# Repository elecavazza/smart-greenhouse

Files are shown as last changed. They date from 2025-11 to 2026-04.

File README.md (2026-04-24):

# smart-greenhouse

Smart GreenHouse System Diagram with Wiring

As part of my Mechatronics Project I will be creating a Smart Automated Greenhouse.  
As part of this project there will be a number of systems:  

* Watering system
  * 5v pump with relay control
  * Water level sensor
  * Reservoir
  * Shower head
  * Soil moisture sensor
* Lighting System
  * 12V Grow LED Strip with relay
* Air Quality System
  * 5V Fan with relay
  * VOC, Temperature, Humidity Sensors
* User Interface
  * Touch screen

## Programming

### CYD ESP32-2432S028

To program the CYD ESP32-2432S028 we will be using Arduino C/C++.  
To upload code to the device we use the Arduino IDE to compile it and the Micro USB connector to upload it via serial.  
To get it to work:  

* upload at a baud rate of 115200  
* target board used is the `ESP32 Dev Module`
* the external dependencies are:  `lvgl`, `TFT_eSPI`, `XPT2046_Touchscreen`
* enable erase all flash on sketch upload

#### Arduino Setup

```bash
Arduino
Version: 2.3.7
Date: 2025-12-17T16:03:27.077Z (3 months ago)
CLI Version: 1.3.1

arduino-cli  Version: 1.4.1 Commit: Homebrew Date: 2026-01-19T16:11:40Z
{}

ID            Installed        Latest           Name
arduino:avr   1.8.6            1.8.7            Arduino AVR Boards
arduino:esp32 2.0.18-arduino.5 2.0.18-arduino.5 Arduino ESP32 Boards
esp32:esp32   3.3.5            3.3.7            esp32

Name                Installed   Available    Location Description
EspSoftwareSerial   8.1.0       -            user     -
lvgl                9.4.0       9.5.0        user     Full-featured Graphics Library for Em...
TFT_eSPI            2.5.43      -            user     -
XPT2046_Touchscreen 1.4         -            user     -

Port                            Protocol Type              Board Name FQBN Core
/dev/cu.Bluetooth-Incoming-Port serial   Serial Port       Unknown
/dev/cu.SoundcoreLifeP3         serial   Serial Port       Unknown
/dev/cu.StrawberryMoon          serial   Serial Port       Unknown
/dev/cu.debug-console           serial   Serial Port       Unknown
/dev/cu.usbserial-210           serial   Serial Port (USB) Unknown
```

```bash
arduino-cli version
arduino-cli config dump
arduino-cli core list
arduino-cli lib list
arduino-cli board list
```

### Raspberry Pi Pico

To program the Raspberry Pi Pico we will be using MicroPython.  
To upload code to the device we use the Thonny IDE and upload via the Micro USB connector.  

## Parts

### Electronics

Relays: 5v, 12, 24v etc:  
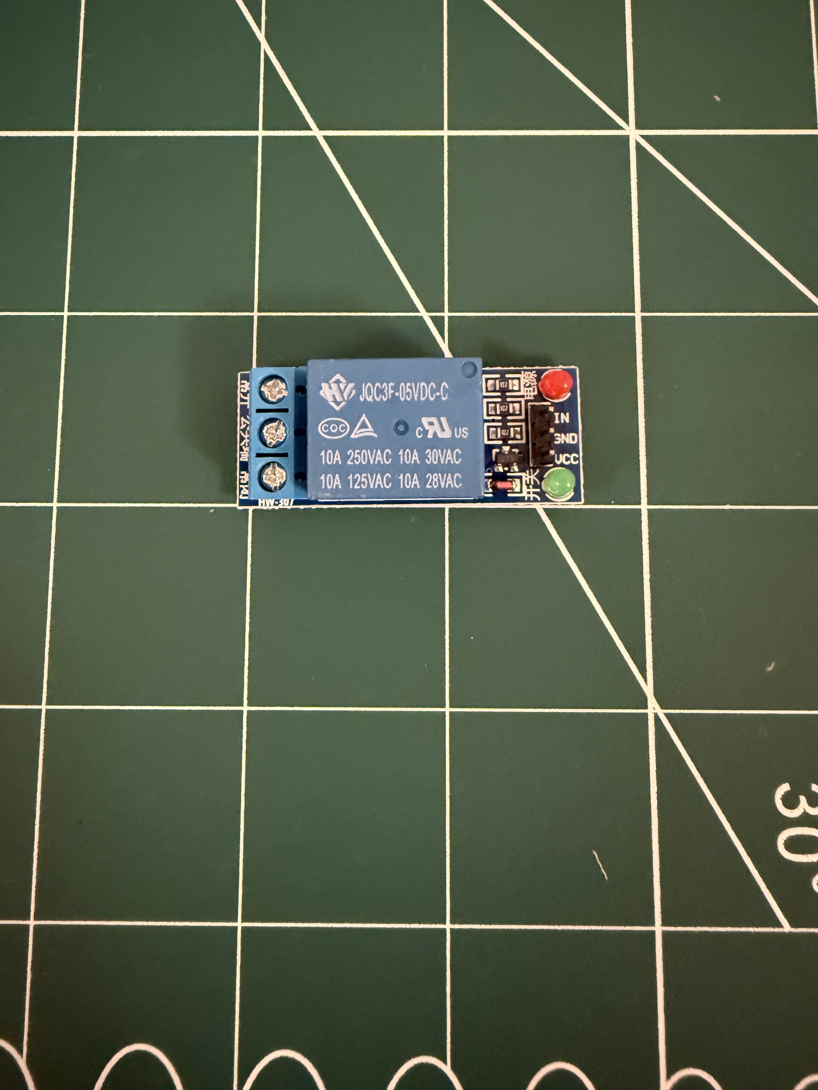
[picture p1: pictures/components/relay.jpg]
relay


5V Led Grow Strip:  
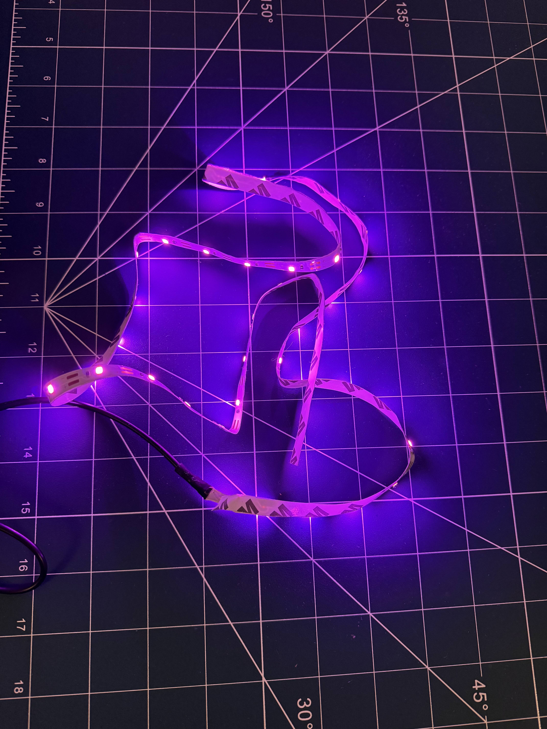
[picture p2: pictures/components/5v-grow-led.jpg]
5v led

12V Led Grow Strip:  
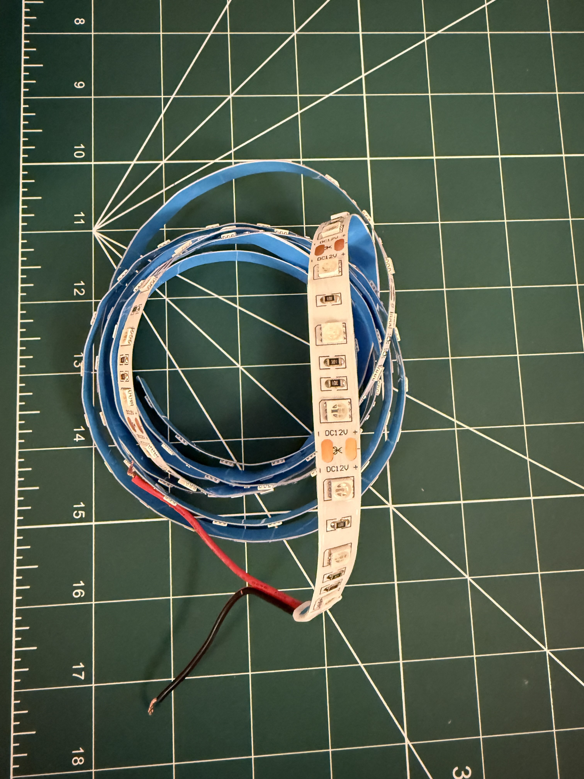
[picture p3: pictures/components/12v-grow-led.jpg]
12v

CO2 Sensor:  
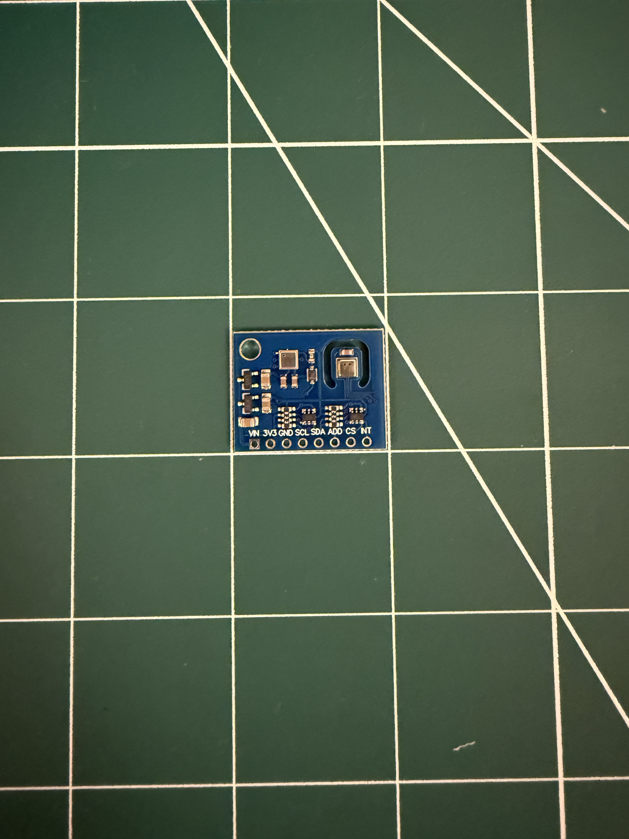
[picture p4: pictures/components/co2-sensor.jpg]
co2 sensor


Soil Moisture Sensor:  
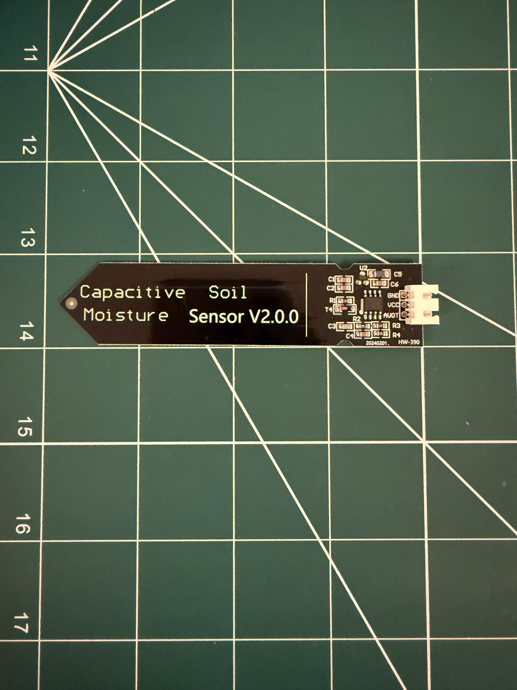
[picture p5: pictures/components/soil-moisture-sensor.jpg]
soil moisture sensor


Submersible Pump:  
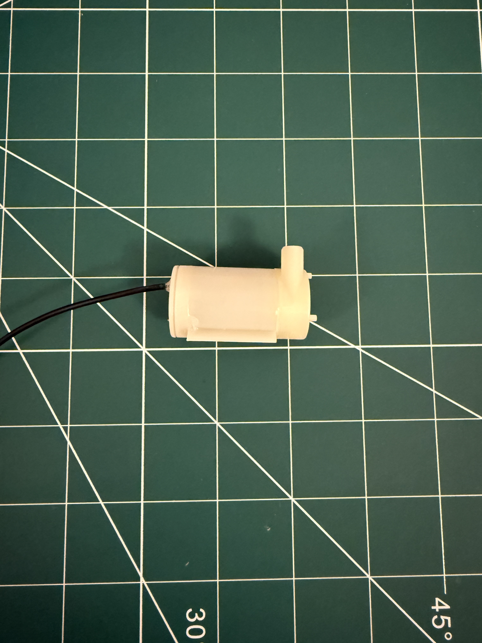
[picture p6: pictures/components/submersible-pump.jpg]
submersible pump


Water Level Sensor:  
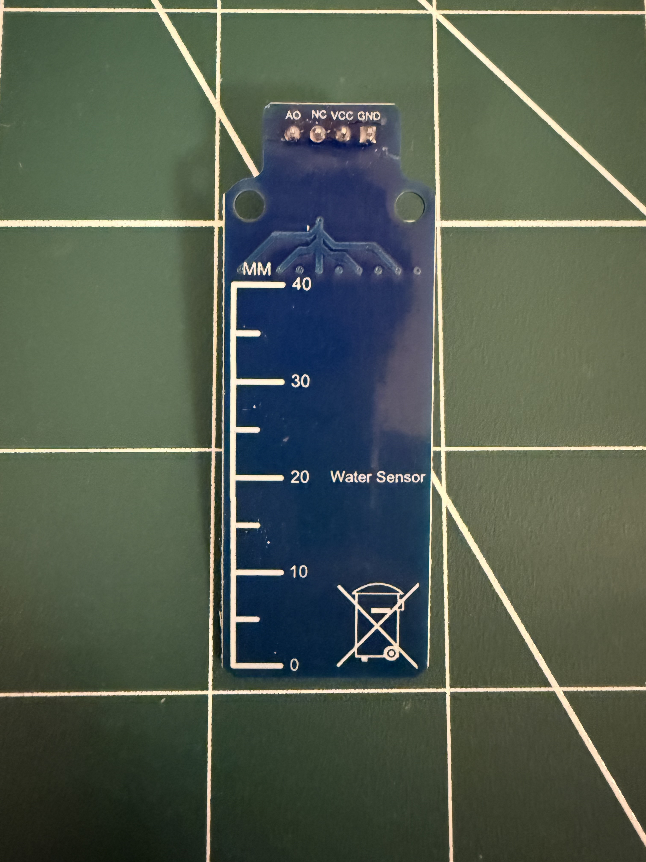
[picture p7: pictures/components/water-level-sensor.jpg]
water-level-sensor


Temperature and Humidity Sensor:  
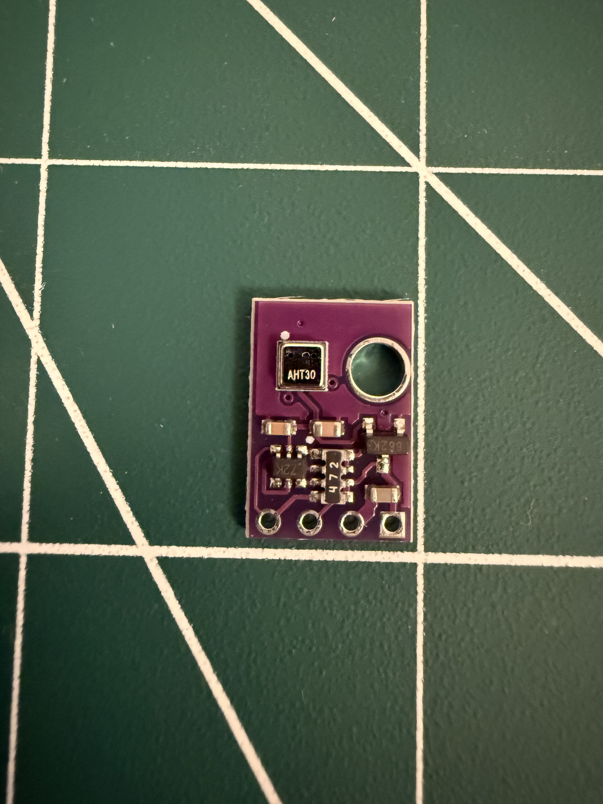
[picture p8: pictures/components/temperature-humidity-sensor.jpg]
temperature-humidity-sensor


### GreenHouse/Plant

Ikea Bittergurka Pot:
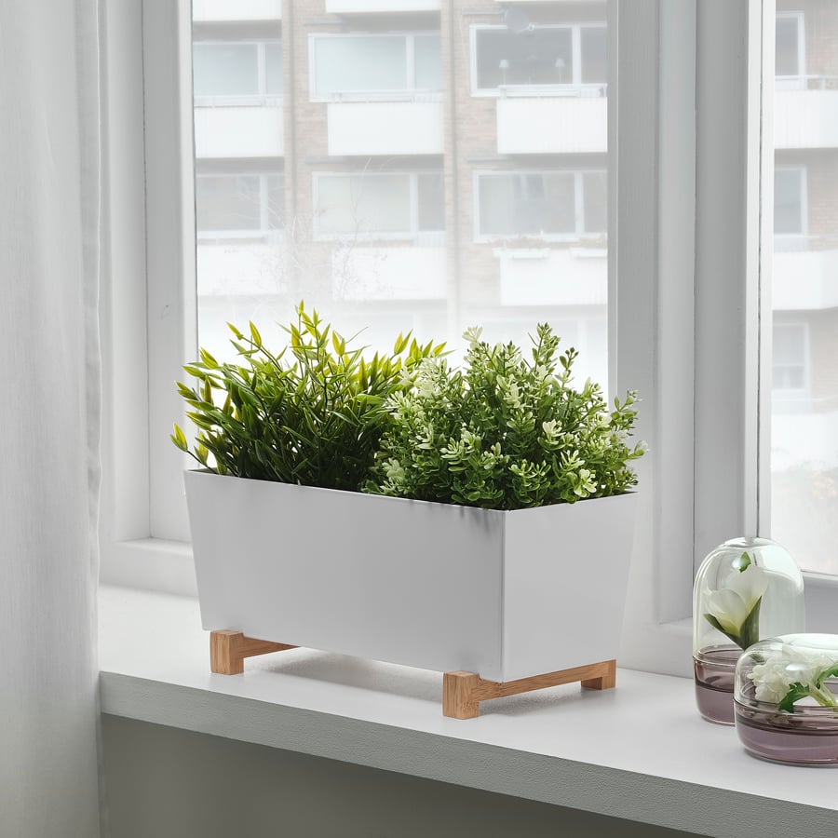
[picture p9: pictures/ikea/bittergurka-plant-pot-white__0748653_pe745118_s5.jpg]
Ikea Bittergurka

Ikea Bittergurka Dimensions

[3D Model](./3d-models/bittergurka-plant-pot-white-80285787.fbx)

Ikea Akerbaer Greenhouse:
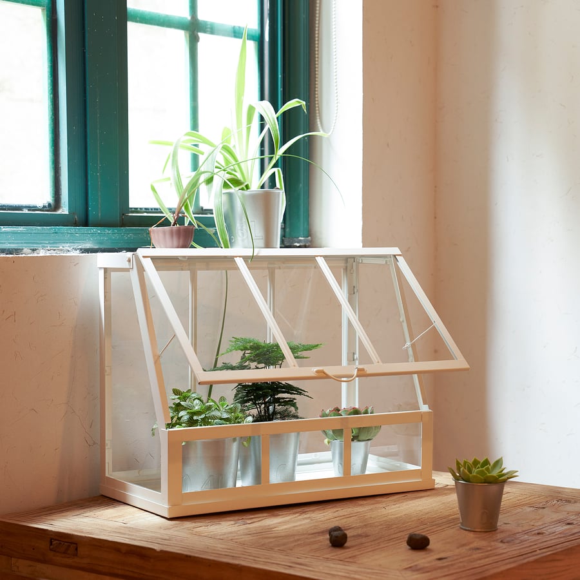
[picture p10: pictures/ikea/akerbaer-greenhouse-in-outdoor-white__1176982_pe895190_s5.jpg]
Ikea Akerbaer

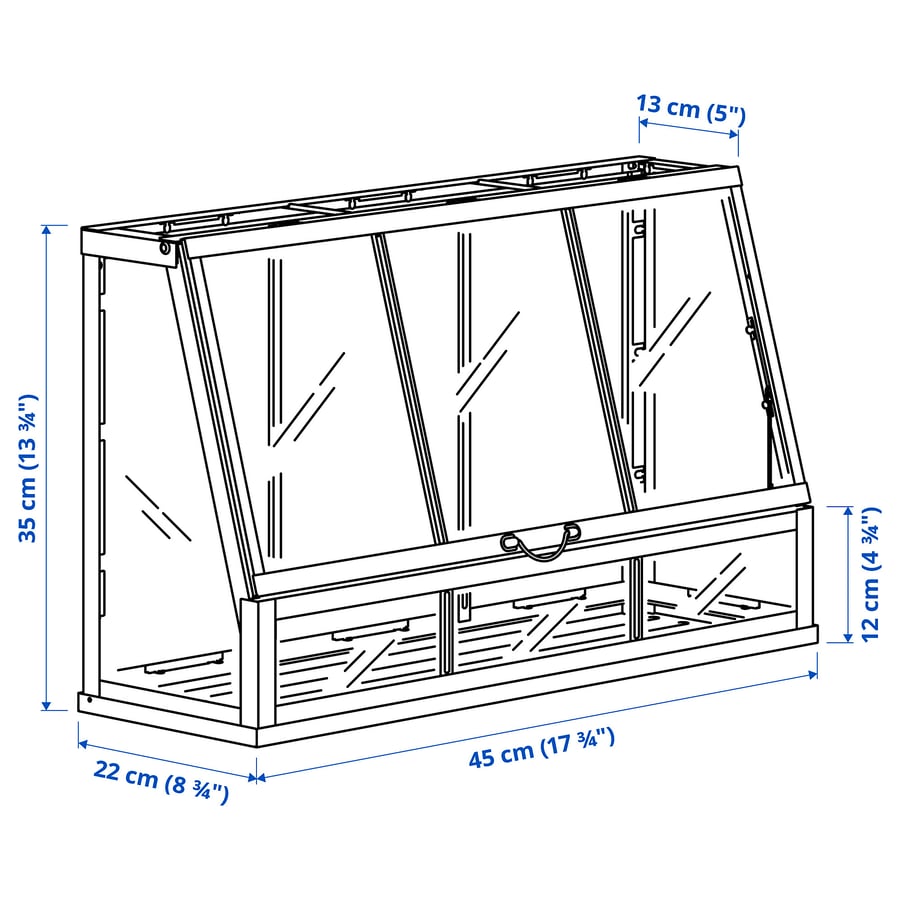
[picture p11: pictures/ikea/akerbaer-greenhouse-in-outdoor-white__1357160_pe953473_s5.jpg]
Ikea Akerbaer Dimensions


[3D Model](./3d-models/akerbar-white-30537170.fbx)

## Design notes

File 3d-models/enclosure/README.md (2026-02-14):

# Enclosure Design

We are currently on revision 2.  
There will need to be atleast one other revision.  

Chnages needed:

* Hole for Soil Sensor Connector
  * 3 pin
* Hole for Light Sensor Connector
  * 2 pin
* Switch to 3 pin for water level
  * Currently using 2 of the 2 pin

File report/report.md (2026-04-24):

# Smart Greenhouse Control System

## Mechatronics Project Report

---

## Table of Contents

1. [Introduction](#1-introduction)
2. [System Architecture](#2-system-architecture)
3. [Hardware Design](#3-hardware-design)
4. [Physical Assembly](#4-physical-assembly)
5. [Software Design](#5-software-design)
6. [Communication Protocol](#6-communication-protocol)
7. [3D Printed Components](#7-3d-printed-components)
8. [Bill of Materials](#8-bill-of-materials)
9. [Challenges & Solutions](#9-challenges--solutions)
10. [Results & Discussion](#10-results--discussion)
11. [Conclusion & Future Work](#11-conclusion--future-work)
12. [References](#12-references)

---

## 1. Introduction

### 1.1 Project Overview

This project presents the design and implementation of a Smart Automated Greenhouse system capable of autonomously maintaining optimal growing conditions for plants. The system integrates multiple sensors, actuators, and microcontrollers to create a closed loop control system that monitors and regulates watering, lighting, and air quality without manual intervention.

### 1.2 Motivation

Indoor herb gardening presents several challenges for hobbyists and enthusiasts:

- **Inconsistent watering**: Over or under watering is a common cause of plant death
- **Inadequate lighting**: Indoor environments often lack sufficient natural light for healthy plant growth
- **Poor air circulation**: Stagnant air can lead to fungal growth and humidity problems

A smart greenhouse addresses these challenges by automating the monitoring and control of environmental conditions, ensuring plants receive optimal care even when the owner is away.

### 1.3 Objectives

The primary objectives of this project were to:

1. **Design and build an automated watering system** that delivers water based on soil moisture levels using pulse based irrigation to prevent overwatering
2. **Implement automatic grow lighting** that supplements natural light when ambient levels are insufficient
3. **Create an air quality management system** that controls temperature and humidity through ventilation
4. **Develop a touchscreen user interface** for monitoring sensor data and controlling system functions
5. **Integrate all subsystems** into a cohesive, reliable, and cost effective solution using readily available components

### 1.4 Target Application

The system is designed for growing culinary herbs such as basil and mint, which have moderate water requirements and benefit from consistent environmental conditions. The IKEA ÅKERBÄR greenhouse provides an aesthetically pleasing enclosure suitable for indoor use.

---

## 2. System Architecture

### 2.1 High Level Overview

The Smart Greenhouse employs a dual microcontroller architecture that separates concerns between user interface and control logic:

```mermaid
flowchart TB
    subgraph UI["User Interface Layer"]
        ESP32["ESP32-2432S028<br/>(Cheap Yellow Display)"]
        Touch["Touch Screen<br/>320x240 LCD"]
        LVGL["LVGL Graphics Library"]
    end
    
    subgraph Control["Control Layer"]
        Pico["Raspberry Pi Pico W"]
        Controller["GreenhouseController"]
    end
    
    subgraph Subsystems["Automated Subsystems"]
        Water["WateringSystem"]
        Air["AirQualitySystem"]
        Light["LightingSystem"]
    end
    
    subgraph Sensors["Sensors"]
        Soil["Soil Moisture<br/>(Capacitive)"]
        WaterLvl["Water Level"]
        LDR["Light Sensor<br/>(LDR)"]
        TempHum["Temp & Humidity<br/>(AHT21)"]
    end
    
    subgraph Actuators["Actuators"]
        Pump["5V Submersible<br/>Pump"]
        Fan["5V Cooling<br/>Fans"]
        LED["12V Grow<br/>LED Strip"]
    end
    
    ESP32 <-->|"UART<br/>115200 baud"| Pico
    Touch --> ESP32
    LVGL --> ESP32
    
    Pico --> Controller
    Controller --> Water & Air & Light
    
    Water --> Soil & WaterLvl
    Water --> Pump
    Air --> TempHum
    Air --> Fan
    Light --> LDR
    Light --> LED
```

### 2.2 Design Rationale

The dual controller architecture was chosen for several reasons:

| Aspect | ESP32 (CYD) | Raspberry Pi Pico W |
|---|---|---|
| **Primary Role** | User Interface | Sensor/Actuator Control |
| **Programming Language** | Arduino C++ | MicroPython |
| **Key Libraries** | LVGL, TFT_eSPI | Machine, Custom Modules |
| **Processing Focus** | Graphics Rendering | Real time Control |
| **Communication** | UART TX/RX | UART TX/RX |

This separation allows:

- The ESP32 to focus on smooth UI rendering without being interrupted by sensor polling
- The Pico to maintain precise timing for sensor readings and actuator control
- Independent development and testing of UI and control logic
- Easier debugging of each subsystem

### 2.3 Subsystem Overview

The system comprises three automated subsystems:

#### Watering System

- **Trigger Condition**: Soil moisture below threshold AND water available in reservoir
- **Action**: Pulse based watering (500ms burst with 30 second cooldown)
- **Safety Feature**: Prevents pumping when reservoir is empty

#### Air Quality System

- **Trigger Conditions**:
  - Temperature > 25°C (too hot)
  - Humidity > 70% (too humid)
  - Humidity < 50% (too dry - circulate air)
- **Action**: Activate ventilation fans
- **Override**: Fan stays off if temperature < 20°C (preserve heat)

#### Lighting System

- **Trigger Condition**: Ambient light below threshold
- **Action**: Activate 12V grow LED strip

---

## 3. Hardware Design

### 3.1 Component Selection

#### 3.1.1 Microcontrollers

**Raspberry Pi Pico W**

- Dual-core ARM Cortex-M0+ @ 133MHz
- 264KB SRAM, 2MB Flash
- 26 GPIO pins with 3 ADC channels
- Built in WiFi (802.11n) for future expansion
- MicroPython support for rapid development

**ESP32-2432S028 (Cheap Yellow Display)**

- ESP32-WROOM-32 module
- Integrated 2.8" 320x240 TFT LCD with ILI9341 driver
- XPT2046 resistive touch controller
- Built in USB Serial for programming
- Cost effective all in one display solution

#### 3.1.2 Sensors

| Sensor | Type | Interface | Purpose |
|---|---|---|---|
| Capacitive Soil Moisture | Analog | ADC (GP26) | Measure soil water content |
| Water Level Sensor | Analog | ADC (GP28) | Monitor reservoir level |
| LDR Light Sensor | Analog | ADC (GP27) | Measure ambient light |
| AHT21 | Digital I2C | GP4/GP5 | Temperature & humidity |

**Sensor Specifications:**

*Capacitive Soil Moisture Sensor*
- Operating Voltage: 3.3V - 5V
- Output: Analog (inversely proportional to moisture)
- Calibration: Air ~65000 ADC, Water ~15000 ADC

*AHT21 Temperature & Humidity Sensor*
- Temperature Range: -40°C to +85°C (±0.3°C accuracy)
- Humidity Range: 0-100% RH (±2% accuracy)
- I2C Address: 0x38

#### 3.1.3 Actuators

| Actuator | Voltage | Control | Purpose |
|---|---|---|---|
| Submersible Pump | 5V | Relay (GP14) | Water delivery |
| Cooling Fans (×2) | 5V | Relay (GP15) | Ventilation |
| Grow LED Strip (2m) | 12V | Relay (GP10) | Supplemental lighting |

### 3.2 Pin Assignments

#### Raspberry Pi Pico W Pin Configuration

```
                    ┌─────────────────────┐
                    │   Raspberry Pi      │
                    │      Pico W         │
                    ├─────────────────────┤
         UART TX ──►│ GP0            GP26 │◄── Soil Moisture (ADC)
         UART RX ──►│ GP1            GP27 │◄── Light Sensor (ADC)
                    │ GND            GP28 │◄── Water Level (ADC)
                    │ GP2            GND  │
                    │ GP3            3V3  │
         I2C SDA ──►│ GP4            VREF │
         I2C SCL ──►│ GP5            GP22 │
                    │ GND            GND  │
                    │ GP6            GP21 │
                    │ GP7            GP20 │
                    │ GP8            GP19 │
                    │ GP9            GP18 │
                    │ GND            GND  │
     Light Relay ──►│ GP10           GP17 │
                    │ GP11           GP16 │
                    │ GP12           GP15 │◄── Fan Relay
                    │ GP13           GP14 │◄── Pump Relay
                    │ GND            GND  │
                    └─────────────────────┘
```

#### ESP32 CYD UART Connection

| ESP32 Pin | Function | Connection |
|---|---|---|
| GPIO 35 (RX_P3) | UART Receive | Pico GP0 (TX) |
| GPIO 22 (TX_P3) | UART Transmit | Pico GP1 (RX) |

### 3.3 Power Distribution

The system uses two USB-C Power Delivery boards to provide multiple voltage rails:

```mermaid
flowchart LR
    subgraph Input["Power Input"]
        USB1["USB-C PD Board 1<br/>(5V Output)"]
        USB2["USB-C PD Board 2<br/>(12V Output)"]
    end
    
    subgraph Rails["Voltage Rails"]
        V3["3.3V Rail<br/>(from Pico)"]
        V5["5V Rail"]
        V12["12V Rail"]
    end
    
    subgraph Loads5V["5V Loads"]
        Pico2["Pico W"]
        ESP["ESP32 CYD"]
        Fans2["Cooling Fans"]
        Pump2["Water Pump"]
        Relay["Relay Modules"]
    end
    
    subgraph Loads12V["12V Loads"]
        LEDStrip["Grow LED Strip"]
    end
    
    subgraph Loads3V["3.3V Loads"]
        Sensors2["Analog Sensors"]
        LevelShift["Level Shifters"]
    end
    
    USB1 --> V5
    USB2 --> V12
    Pico2 --> V3
    
    V5 --> Pico2 & ESP & Fans2 & Pump2 & Relay
    V12 --> LEDStrip
    V3 --> Sensors2 & LevelShift
```

### 3.4 Level Shifting

The 5V relay modules require 5V logic signals, but the Pico W operates at 3.3V. Bidirectional level shifters are used to convert:

- 3.3V Pico GPIO → 5V Relay trigger signals

---

## 4. Physical Assembly

### 4.1 Greenhouse Structure

The project utilises IKEA furniture as the foundation:

**IKEA ÅKERBÄR Greenhouse**
- Dimensions: 45 × 22 × 35 cm
- Material: Powder coated steel with glass panels
- Provides enclosed environment with ventilation options
- Price: €19.00

**IKEA BITTERGURKA Plant Pot**
- Dimensions: 32 × 15 × 15 cm
- Material: Powder coated steel
- Positioned centrally within greenhouse
- Price: €12.00

### 4.2 Component Placement

```mermaid
flowchart TB
    subgraph Greenhouse["IKEA ÅKERBÄR Greenhouse (Front View)"]
        subgraph Top["Top Section"]
            CYD["ESP32 CYD Display<br/>(On top of greenhouse)"]
            LEDs["12V Grow LED Strip"]
            LDRTop["Light Sensor (LDR)"]
        end
        
        subgraph Middle["Middle Section"]
            Pot["BITTERGURKA Pot<br/>with Basil Plant"]
            SoilSensor["Soil Moisture Sensor"]
            Showerhead["Magnetic Showerhead"]
        end
        
        subgraph Back["Back Wall (Interior)"]
            FansBack["Cooling Fans (×2)"]
        end
        
        subgraph Right["Right Side"]
            Reservoir["Glass Jar Reservoir"]
            PumpR["Submersible Pump"]
            WaterSensorR["Water Level Sensor"]
        end
    end
    
    subgraph External["External (Back of Greenhouse)"]
        Enclosure["Project Box Enclosure"]
    end
    
    Top --> Middle
    Middle --> Right
    Back --> Middle
    Greenhouse --> External
```

### 4.3 Enclosure Contents

The 3D printed project box mounted on the back of the greenhouse contains:

| Component | Purpose |
|---|---|
| Breadboard | Component interconnection |
| Raspberry Pi Pico W | Main controller |
| Level Shifters | 3.3V ↔ 5V conversion |
| Relay Modules (×3) | Pump, Fan, LED control |
| AHT21 Sensor | Temperature & humidity monitoring |
| USB-C PD Board (5V) | 5V power supply |
| USB-C PD Board (12V) | 12V power supply |

### 4.4 Wiring Strategy

**Connector Types:**
- **JST Connectors**: Used throughout for modularity and easy disconnection
- **RJ45 Keystone Jacks**: Used for longer cable runs (CYD power/data, LED/LDR)

**Cable Routing:**
- All wires routed under the back wall to the enclosure underside
- Standard white Ethernet cabling for RJ45 connections
- 24 AWG white wire for general connections

**RJ45 Usage:**
1. **CYD Connection**: Power (5V, GND) + Data (UART TX, RX)
2. **LED/LDR Connection**: 12V, GND, LDR signal

---

## 5. Software Design

### 5.1 Raspberry Pi Pico W (MicroPython)

#### 5.1.1 Software Architecture

The Pico software follows a modular, object oriented design:

```mermaid
classDiagram
    class main {
        +main()
    }
    
    class GreenhouseController {
        -uart: UARTCommunication
        -wateringSystem: WateringSystem
        -airQualitySystem: AirQualitySystem
        -lightingSystem: LightingSystem
        -led: Pin
        +run()
        +sendAllSensorData()
        +sendAllStatus()
        -_processCommands()
        -_handleCommand()
        -_readAllSensors()
        -_updateSystems()
    }
    
    class WateringSystem {
        -pump: Relay
        -soilSensor: SoilMoistureSensor
        -waterLevelSensor: WaterLevelSensor
        -enabled: bool
        +enable()
        +disable()
        +update()
        +pulse()
        +getSoilMoisturePercent()
        +getWaterLevelPercent()
    }
    
    class AirQualitySystem {
        -fan: Relay
        -sensor: TemperatureAndHumiditySensor
        -enabled: bool
        +enable()
        +disable()
        +update()
        +getTemperature()
        +getHumidity()
    }
    
    class LightingSystem {
        -light: Relay
        -sensor: LightSensor
        -enabled: bool
        +enable()
        +disable()
        +update()
        +getLightLevelPercent()
    }
    
    class UARTCommunication {
        -uart: UART
        +send()
        +sendSensorData()
        +sendStatus()
        +receive()
        +receiveAll()
    }
    
    class Relay {
        -pin: Pin
        -active_low: bool
        +turnOn()
        +turnOff()
    }
    
    main --> GreenhouseController
    GreenhouseController --> WateringSystem
    GreenhouseController --> AirQualitySystem
    GreenhouseController --> LightingSystem
    GreenhouseController --> UARTCommunication
    WateringSystem --> Relay
    AirQualitySystem --> Relay
    LightingSystem --> Relay
```

#### 5.1.2 Main Control Loop

The main control loop executes the following sequence:

```python
while True:
    # 1. Process incoming UART commands from ESP32
    _processCommands()
    
    # 2. Read sensors periodically (every 2 seconds)
    if time_since_last_read >= SENSOR_READ_INTERVAL_MS:
        _readAllSensors()
    
    # 3. Run automatic control logic for all enabled systems
    wateringSystem.update()
    airQualitySystem.update()
    lightingSystem.update()
    
    # 4. Send data to ESP32 periodically (every 5 seconds)
    if time_since_last_send >= DATA_SEND_INTERVAL_MS:
        sendAllSensorData()
    
    # 5. Small delay to prevent busy loop
    time.sleep_ms(100)
```

#### 5.1.3 Control Algorithms

**Watering System - Pulse Irrigation:**

```python
def update(self):
    if not self.enabled:
        return
    
    # Check conditions
    if not self.isSoilDry():
        return  # Soil is moist enough
    
    if not self.hasWater():
        return  # Reservoir empty - safety check
    
    if time_since_last_pulse < PUMP_COOLDOWN_MS:
        return  # Still in cooldown period
    
    # Perform pulse watering
    self.pulse()  # 500ms burst

def pulse(self):
    self.pump.turnOn()
    time.sleep_ms(PUMP_PULSE_MS)  # 500ms
    self.pump.turnOff()
    self.lastPulseTime = time.ticks_ms()
```

**Air Quality System - Threshold Based Control:**

| Condition | Action | Reason |
|---|---|---|
| Temp > 25°C | Fan ON | Too hot |
| Temp < 20°C | Fan OFF | Preserve heat |
| Humidity > 70% | Fan ON | Too humid |
| Humidity < 50% | Fan ON | Circulate air |
| Otherwise | Fan OFF | Conditions optimal |

**Lighting System - Light Level Control:**

```python
def update(self):
    if not self.enabled:
        return
    
    rawValue = self.sensor.readRaw()
    isDark = rawValue < LIGHT_LOW_THRESHOLD
    
    if isDark:
        self._setLight(True)   # Turn on grow light
    else:
        self._setLight(False)  # Natural light sufficient
```

#### 5.1.4 Configuration Parameters

Key thresholds and timing values defined in [`config.py`](../code/raspberry-pi-pico/main/config.py):

| Parameter | Value | Description |
|---|---|---|
| `SOIL_DRY_THRESHOLD` | 40000 | ADC value indicating dry soil |
| `WATER_LOW_THRESHOLD` | 15000 | ADC value indicating empty reservoir |
| `TEMP_HIGH_THRESHOLD` | 25.0°C | Temperature to trigger cooling |
| `TEMP_LOW_THRESHOLD` | 20.0°C | Temperature to preserve heat |
| `HUMIDITY_HIGH_THRESHOLD` | 70% | Humidity to trigger ventilation |
| `HUMIDITY_LOW_THRESHOLD` | 50% | Low humidity threshold |
| `LIGHT_LOW_THRESHOLD` | 1000 | ADC value indicating darkness |
| `PUMP_PULSE_MS` | 500ms | Duration of pump burst |
| `PUMP_COOLDOWN_MS` | 30000ms | Minimum time between pulses |
| `SENSOR_READ_INTERVAL_MS` | 2000ms | Sensor polling interval |
| `DATA_SEND_INTERVAL_MS` | 5000ms | ESP32 update interval |

### 5.2 ESP32 CYD (Arduino/LVGL)

#### 5.2.1 User Interface Design

The touch screen interface uses the LVGL (Light and Versatile Graphics Library) to provide three main screens:

**Dashboard Tab**: Sensor Readings Display:

- Temperature (°C)
- Humidity (%)
- Soil Moisture (%)
- Water Level (%)

**Auto Tab**: Automatic System Control:

- Watering System toggle (enable/disable automatic control)
- Lighting System toggle
- Air Quality System toggle
- Status indicators (LED on/off)
- Trigger condition descriptions

**Manual Tab**: Direct Device Control:

- LED toggle (on/off)
- Fan toggle (on/off)
- Pump pulse trigger (momentary button)

#### 5.2.2 UI Implementation

```cpp
void create_gui() {
    tabview = lv_tabview_create(lv_screen_active());
    lv_tabview_set_tab_bar_size(tabview, 26);

    lv_obj_t *dash = lv_tabview_add_tab(tabview, "Dashboard");
    lv_obj_t *ctrl = lv_tabview_add_tab(tabview, "Auto");
    lv_obj_t *opts = lv_tabview_add_tab(tabview, "Manual");

    create_dashboard(dash);  // Sensor readings
    create_auto(ctrl);       // System toggles
    create_manual(opts);     // Direct controls
}
```

#### 5.2.3 Dependencies

| Library | Version | Purpose |
|---|---|---|
| LVGL | 9.4.0 | Graphics rendering |
| TFT_eSPI | 2.5.43 | Display driver |
| XPT2046_Touchscreen | 1.4 | Touch input |

---

## 6. Communication Protocol

### 6.1 UART Configuration

| Parameter | Value |
|---|---|
| Baud Rate | 115200 |
| Data Bits | 8 |
| Parity | None |
| Stop Bits | 1 |
| Line Terminator | `\n` (newline) |

### 6.2 Message Format

All messages are ASCII text terminated with a newline character.

#### 6.2.1 Sensor Data (Pico → ESP32)

```
SENSOR:<TYPE>:<VALUE>
```

| Type | Example | Description |
|---|---|---|
| TEMP | `SENSOR:TEMP:24.5` | Temperature in °C |
| HUMIDITY | `SENSOR:HUMIDITY:65.0` | Relative humidity % |
| SOIL | `SENSOR:SOIL:45.0` | Soil moisture % |
| WATER | `SENSOR:WATER:80.0` | Water level % |

#### 6.2.2 Status Updates (Pico → ESP32)

```
STATUS:<SYSTEM>:<STATE>
```

| System | States | Example |
|---|---|---|
| WATER | ON/OFF | `STATUS:WATER:ON` |
| LIGHT | ON/OFF | `STATUS:LIGHT:OFF` |
| AIR | ON/OFF | `STATUS:AIR:ON` |

#### 6.2.3 Commands (ESP32 → Pico)

**Request Commands:**
| Command | Response |
|---|---|
| `REQ:SENSORS` | All sensor data |
| `REQ:STATUS` | All system statuses |

**System Control Commands:**
| Command | Action |
|---|---|
| `CMD:WATER:ON` | Enable watering system |
| `CMD:WATER:OFF` | Disable watering system |
| `CMD:LIGHT:ON` | Enable lighting system |
| `CMD:LIGHT:OFF` | Disable lighting system |
| `CMD:AIR:ON` | Enable air quality system |
| `CMD:AIR:OFF` | Disable air quality system |

**Manual Device Commands:**
| Command | Action |
|---|---|
| `CMD:LED:ON` | Turn grow LED on |
| `CMD:LED:OFF` | Turn grow LED off |
| `CMD:FAN:ON` | Turn fan on |
| `CMD:FAN:OFF` | Turn fan off |
| `CMD:PUMP:PULSE` | Trigger pump pulse |

### 6.3 Communication Flow

```mermaid
sequenceDiagram
    participant ESP32 as ESP32 (UI)
    participant Pico as Pico (Controller)
    participant Sensors
    participant Actuators

    Note over ESP32,Pico: Startup Sequence
    Pico->>ESP32: PICO:READY
    ESP32->>Pico: REQ:SENSORS
    ESP32->>Pico: REQ:STATUS
    
    Note over ESP32,Pico: Normal Operation (every 5s)
    Pico->>Sensors: Read all sensors
    Sensors-->>Pico: Sensor values
    Pico->>ESP32: SENSOR:TEMP:24.5
    Pico->>ESP32: SENSOR:HUMIDITY:65.0
    Pico->>ESP32: SENSOR:SOIL:45.0
    Pico->>ESP32: SENSOR:WATER:80.0
    
    Note over ESP32,Pico: User Interaction
    ESP32->>Pico: CMD:WATER:ON
    Pico->>Actuators: Enable watering system
    Pico->>ESP32: STATUS:WATER:ON
    
    Note over ESP32,Pico: Manual Control
    ESP32->>Pico: CMD:PUMP:PULSE
    Pico->>Actuators: Pump ON (500ms)
    Pico->>Actuators: Pump OFF
```

---

## 7. 3D Printed Components

### 7.1 Electronics Enclosure

The electronics enclosure was designed using **OpenSCAD** with the **YAPP (Yet Another Parametric Projectbox)** generator library.

#### 7.1.1 Design Evolution

| Version | Changes |
|---|---|
| v1 | Initial design with basic dimensions |
| v2 | Adjusted internal standoffs |
| v3 | Final version with connector cutouts |

#### 7.1.2 Features

- Parametric design allowing easy modifications
- Separate lid and base for easy assembly
- Cutouts for:
  - RJ45 keystone jacks
  - JST connectors
  - Ventilation

#### 7.1.3 Files

- [`design-v3.scad`](../3d-models/enclosure/design-v3.scad) - OpenSCAD source
- [`design-v3-bottom.stl`](../3d-models/enclosure/design-v3-bottom.stl) - Base STL
- [`design-v3-lid.stl`](../3d-models/enclosure/design-v3-lid.stl) - Lid STL

#### 7.1.4 Planned Improvements

As noted in the enclosure README, future revisions will add:

- Hole for soil sensor connector (3-pin)
- Hole for light sensor connector (2-pin)
- Switch water level connector to 3-pin (currently using 2× 2-pin)

### 7.2 Showerhead

A custom showerhead was designed using **Fusion 360** for even water distribution over the soil surface.

#### 7.2.1 Design Specifications

- **Shape**: Rectangular box with internal cavity
- **Water Inlet**: Hollow cylinder into cavity
- **Water Outlets**: Holes drilled in bottom (post-printing)
- **Mounting**: Magnets glued to 3D model for easy attachment/removal

#### 7.2.2 Attachment Method

Magnets are glued to the showerhead body, allowing it to:

- Attach securely to the steel BITTERGURKA pot rim
- Be easily removed for cleaning or maintenance
- Self align with the planting area

---

## 8. Bill of Materials

### 8.1 Complete Parts List

| Item | Source | Qty | Unit Cost (€) | Total (€) |
|---|---|-----|---|---|
| 5V Relay | AliExpress | 2 | 1.50 | 3.00 |
| Soil Moisture Sensor | AliExpress | 5 | - | 3.23 |
| 12V Grow LED (2m) | AliExpress | 1 | 3.55 | 3.55 |
| 24 AWG White Wire (5m) | AliExpress | 1 | 2.34 | 2.34 |
| Cheap Yellow Display (CYD) | AliExpress | 1 | 9.99 | 9.99 |
| 5V Fans | Amazon | 2 | - | 6.54 |
| 5V Submersible Pumps | Amazon | 5 | - | 6.99 |
| Tubing | AliExpress | 1 | 2.00 | 2.00 |
| Water Level Sensors | AliExpress | 5 | - | 2.18 |
| RJ45 Keystone Jack | Temu | 10 | - | 5.08 |
| Adhesive Cable Clips | Temu | 50 | - | 1.72 |
| Heat Shrink Sleeve | Temu | 580 | - | 2.69 |
| Welding Heat Shrink | Temu | 1 | - | 4.91 |
| JST Connectors and Cables | Temu | 1 | - | 4.76 |
| Breadboard | Temu | 1 | - | 1.19 |
| USB-C PD Board | AliExpress | 5 | - | 4.71 |
| Temp/Humidity/CO2 Sensor (ENS160+AHT21) | AliExpress | 1 | - | 4.85 |
| Pi Pico | AliExpress | 5 | - | 9.00 |
| Level Shifter | AliExpress | 10 | - | 2.28 |
| IKEA BITTERGURKA Plant Pot | IKEA | 1 | 12.00 | 12.00 |
| IKEA ÅKERBÄR Greenhouse | IKEA | 1 | 19.00 | 19.00 |

### 8.2 Cost Summary

| Category | Cost (€) |
|---|---|
| Electronics & Sensors | €66.26 |
| Wiring & Connectors | €19.16 |
| Mechanical (IKEA) | €31.00 |
| **TOTAL** | **€112.01** |

*Note: Some items purchased in bulk quantities for spare parts and future projects.*

---

## 9. Challenges & Solutions

### 9.1 Electrical Challenges

#### 9.1.1 Loose Connections

**Problem**: Intermittent issues caused by loose wire connections on the breadboard, leading to unreliable sensor readings and actuator control.

**Solution**: Implemented cable clamps and strain relief to ensure secure, consistent connections. JST connectors were added at key points for modularity while maintaining connection integrity.

#### 9.1.2 USB-PD Power Compatibility

**Problem**: Not all USB power bricks properly support USB Power Delivery for the 12V rail needed by the LED strip. One power supply incorrectly output 15V, risking damage to components.

**Solution**: Tested multiple power supplies to identify compatible units. Selected verified USB-PD chargers that correctly negotiate and output 12V. Always verify output voltage before connecting loads.

#### 9.1.3 Power Surge Serial Issues

**Problem**: Power surges when actuators switch caused serial logging output to break, making debugging difficult. This occurred due to a single 5V line powering the Pico, ESP32, fans, relays, and pump.

**Solution**:  

- Added decoupling capacitors near sensitive components
- Ensured solid ground connections
- Considered separate power paths for high current loads in future revisions

#### 9.1.4 Relay Voltage Mismatch

**Problem**: Purchased 5V relay modules but the Pico W outputs 3.3V GPIO signals, insufficient to trigger the relays.

**Solution**: Implemented level shifters (3.3V to 5V) between the Pico GPIO pins and relay trigger inputs. This ensures reliable relay switching while maintaining proper logic levels.

### 9.2 Mechanical Challenges

#### 9.2.1 JST Connector Pin Length

**Problem**: Female JST connector pins were too short to make proper contact when inserted into the breadboard, causing intermittent connections.

**Solution**: Extended pins using jumper wires soldered to the JST connectors, or used adapter boards. For critical connections, switched to direct soldering with heat shrink insulation.

### 9.3 Integration Challenges

#### 9.3.1 System Integration Testing

**Problem**: Combining multiple subsystems revealed interaction issues not present during individual testing.

**Solution**: Adopted an incremental integration strategy:

1. Test each sensor/actuator individually on separate breadboards
2. Integrate one subsystem at a time with the main controller
3. Test communication with the ESP32 after each subsystem addition
4. Final full system integration testing

### 9.4 What Worked Well

#### 9.4.1 3D Enclosure Design

The YAPP (Yet Another Parametric Projectbox) system proved to be:

- Very intuitive to use
- Easy to iterate designs quickly
- Well documented with clear examples
- Flexible enough to accommodate various connector cutouts

#### 9.4.2 Showerhead Design

The custom showerhead designed in Fusion 360 was straightforward:

- Simple rectangular box geometry with internal cavity
- Hollow cylinder for water inlet
- Holes drilled post printing for water outlets
- Magnetic mounting system works reliably

---

## 10. Results & Discussion

### 10.1 System Performance

The completed Smart Greenhouse system successfully achieves all primary objectives:

| Objective | Status | Notes |
|---|---|---|
| Automated Watering | Achieved | Pulse irrigation prevents overwatering |
| Automatic Lighting | Achieved | Responds to ambient light levels |
| Air Quality Control | Achieved | Temperature and humidity regulation |
| Touch Screen Interface | Achieved | Dashboard, Auto, and Manual modes |
| System Integration | Achieved | All subsystems work together |

### 10.2 Operational Observations

**Watering System:**

- Pulse based irrigation effectively maintains soil moisture
- 30 second cooldown prevents water logging
- Water level sensor successfully prevents dry pump operation

**Lighting System:**

- 12V grow LED provides adequate supplemental light
- Light sensor correctly detects ambient conditions
- Active high relay configuration works reliably

**Air Quality System:**

- Temperature and humidity readings are accurate
- Fan activation effectively circulates air
- Threshold based control maintains stable conditions

### 10.3 Plant Growth

The system has been successfully used to grow basil and mint herbs. The automated care has resulted in consistent growth without manual intervention.

### 10.4 Photos

*[Placeholder for project photos to be added]*

- Overall greenhouse setup
- Electronics enclosure interior
- ESP32 display showing dashboard
- Plant growth progress

---

## 11. Conclusion & Future Work

### 11.1 Conclusion

This project successfully demonstrates the design and implementation of a Smart Automated Greenhouse system for indoor herb cultivation. The dual microcontroller architecture effectively separates user interface concerns from real time control, resulting in a responsive and reliable system.

Key achievements include:

- **Modular software design** enabling independent development and testing of subsystems
- **Cost effective solution** at €112.01 using readily available components
- **User friendly interface** with touch screen control and monitoring
- **Reliable automation** of watering, lighting, and ventilation

The project provided valuable experience in:

- Embedded systems programming (MicroPython and Arduino)
- Sensor integration and calibration
- Communication protocol design
- 3D printing and mechanical design
- System integration and debugging

### 11.2 Future Work

Several enhancements are planned for future development:

#### 11.2.1 Smart Home Integration

- **ESPHome Migration**: Rewrite firmware using ESPHome for seamless integration with Home Assistant
- **Apple HomeKit**: Enable control via Apple Home app using HomeKit protocol
- **Voice Control**: Add Siri/Alexa voice commands for system control

#### 11.2.2 Data Logging & Visualisation

- **Historical Data**: Store sensor readings over time in a database
- **Graphing**: Display temperature, humidity, and soil moisture trends
- **Alerts**: Push notifications for low water level or system faults

#### 11.2.3 Plant Monitoring

- **Camera Integration**: Add camera module to capture time lapse of plant growth
- **Image Analysis**: Potential for plant health monitoring using computer vision

#### 11.2.4 Hardware Improvements

- **Wiring Refinement**: Cleaner cable management and professional grade connectors
- **CO2 Monitoring**: Integrate the ENS160 sensor (already purchased) for air quality monitoring
- **Multi Zone Support**: Expand to support multiple plant pots with individual control

---

## 12. References

### 12.1 Hardware Documentation

- [Raspberry Pi Pico W Datasheet](https://datasheets.raspberrypi.com/picow/pico-w-datasheet.pdf)
- [ESP32-WROOM-32 Datasheet](https://www.espressif.com/sites/default/files/documentation/esp32-wroom-32_datasheet_en.pdf)
- [AHT21 Temperature & Humidity Sensor](https://asairsensors.com/product/aht21-sensor/)
- [ILI9341 LCD Controller](https://www.displayfuture.com/Display/datasheet/controller/ILI9341.pdf)

### 12.2 Software Libraries

- [LVGL - Light and Versatile Graphics Library](https://lvgl.io/)
- [TFT_eSPI Arduino Library](https://github.com/Bodmer/TFT_eSPI)
- [MicroPython Documentation](https://docs.micropython.org/en/latest/)
- [YAPP Projectbox Generator](https://github.com/mrWheel/YAPP_Box)

### 12.3 Component Sources

- [IKEA ÅKERBÄR Greenhouse](https://www.ikea.com/ie/en/p/akerbaer-greenhouse-in-outdoor-white-30537170/)
- [IKEA BITTERGURKA Plant Pot](https://www.ikea.com/ie/en/p/bittergurka-plant-pot-white-80285787/)

---

## Appendices

### Appendix A: Pin Configuration Summary

#### Raspberry Pi Pico W

| GPIO | Function | Component |
|---|---|---|
| GP0 | UART TX | ESP32 RX |
| GP1 | UART RX | ESP32 TX |
| GP4 | I2C SDA | AHT21 Sensor |
| GP5 | I2C SCL | AHT21 Sensor |
| GP10 | Relay Output | Grow LED (Active HIGH) |
| GP14 | Relay Output | Water Pump (Active LOW) |
| GP15 | Relay Output | Cooling Fan (Active LOW) |
| GP26 | ADC Input | Soil Moisture Sensor |
| GP27 | ADC Input | Light Sensor (LDR) |
| GP28 | ADC Input | Water Level Sensor |

#### ESP32 CYD

| GPIO | Function | Component |
|---|---|---|
| GPIO 22 | UART TX (P3) | Pico RX |
| GPIO 35 | UART RX (P3) | Pico TX |

### Appendix B: UART Protocol Quick Reference

```
# Sensor Data (Pico → ESP32)
SENSOR:TEMP:<value>       # Temperature °C
SENSOR:HUMIDITY:<value>   # Humidity %
SENSOR:SOIL:<value>       # Soil moisture %
SENSOR:WATER:<value>      # Water level %

# Status (Pico → ESP32)
STATUS:WATER:ON|OFF
STATUS:LIGHT:ON|OFF
STATUS:AIR:ON|OFF

# Requests (ESP32 → Pico)
REQ:SENSORS               # Request all sensor data
REQ:STATUS                # Request all system status

# System Control (ESP32 → Pico)
CMD:WATER:ON|OFF          # Enable/disable watering system
CMD:LIGHT:ON|OFF          # Enable/disable lighting system
CMD:AIR:ON|OFF            # Enable/disable air quality system

# Manual Control (ESP32 → Pico)
CMD:LED:ON|OFF            # Direct LED control
CMD:FAN:ON|OFF            # Direct fan control
CMD:PUMP:PULSE            # Trigger pump pulse
```

### Appendix C: File Structure

```
smart-greenhouse/
├── 3d-models/
│   ├── enclosure/
│   │   ├── design-v3.scad
│   │   ├── design-v3-bottom.stl
│   │   ├── design-v3-lid.stl
│   │   └── library/
│   │       └── YAPPgenerator_v3.scad
│   ├── akerbar-white-30537170.fbx
│   └── bittergurka-plant-pot-white-80285787.fbx
├── code/
│   ├── esp32-display/
│   │   └── main/
│   │       └── main.ino
│   └── raspberry-pi-pico/
│       └── main/
│           ├── main.py
│           ├── GreenhouseController.py
│           ├── WateringSystem.py
│           ├── AirQualitySystem.py
│           ├── LightingSystem.py
│           ├── UARTCommunication.py
│           ├── Relay.py
│           ├── SoilMoistureSensor.py
│           ├── WaterLevelSensor.py
│           ├── LightSensor.py
│           ├── TemperatureAndHumiditySensor.py
│           └── config.py
├── firmware/
│   └── MICROPYTHON_RPI_PICO_W-20251209-v1.27.0.uf2
├── parts/
│   └── parts-list-and-cost.csv
├── pictures/
│   ├── components/
│   ├── ikea/
│   └── pin-outs/
├── report/
│   └── report.md
└── README.md
```

---

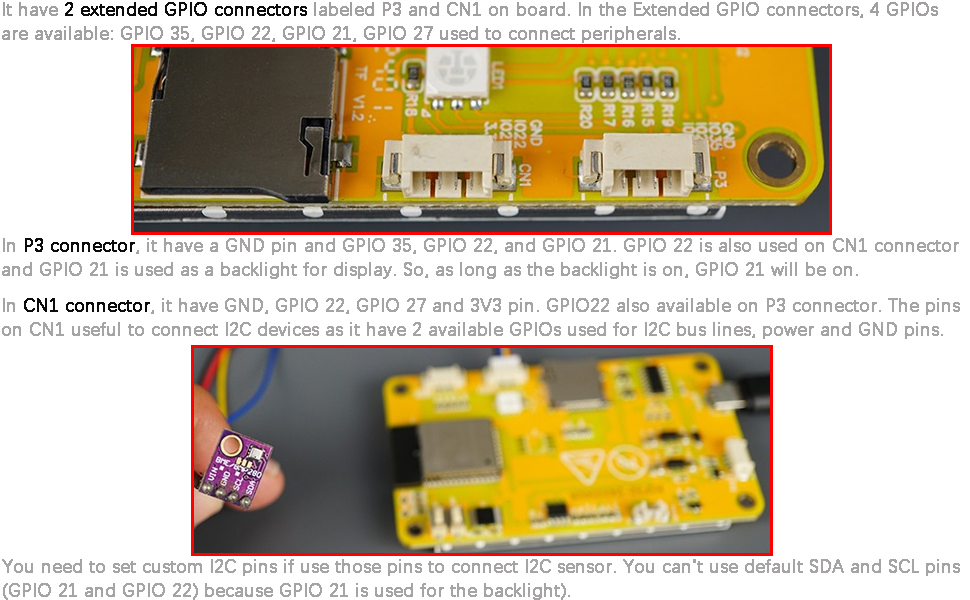
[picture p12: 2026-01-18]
pictures/pin-outs/cyd-esp32-2432S028-io-part-2.png

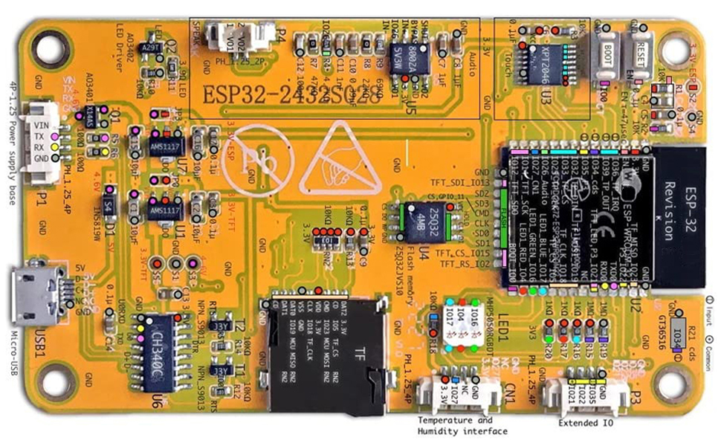
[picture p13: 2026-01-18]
pictures/pin-outs/cyd-esp32-2432S028-pin-out.png

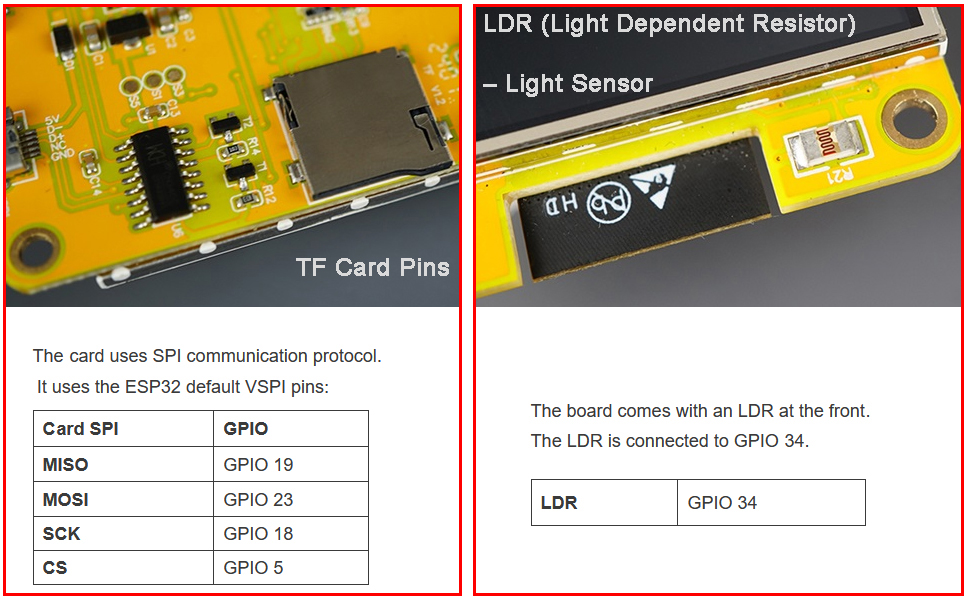
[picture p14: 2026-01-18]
pictures/pin-outs/cyd-esp32-2432S028-io-part-1.png

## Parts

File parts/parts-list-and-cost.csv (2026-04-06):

Items | Source | Link | Number of Units | Cost Per Unit (€) | Full Cost (€)
5V Relay | Aliexpress | https://a.aliexpress.com/_EwlqgFq | 2 | 1.50 | 3
Soil Moisture Sensor | Aliexpress | https://a.aliexpress.com/_Ev2ZaBm | 5 |  | 3.23
12V Grow LED (2m) | Aliexpress | https://a.aliexpress.com/_EyjLxdW | 1 | 3.55 | 3.55
24 AWG White Wire (5m) | Aliexpress | https://a.aliexpress.com/_EjvKJsU | 1 | 2.34 | 2.34
Cheap Yellow Display | Aliexpress | https://a.aliexpress.com/_EweokIy | 1 | 9.99 | 9.99
5V Fans | Amazon | https://www.amazon.ie/dp/B0DQ4VGPN1?ref=ppx_pop_mob_ap_share | 2 |  | 6.54
5V Pumps | Amazon | https://www.amazon.ie/dp/B07F9MT92K?ref=ppx_pop_mob_ap_share | 5 |  | 6.99
Tubing | Aliexpress | Listing Gone | 1 | 2 | 2
Water Level Sensors | Aliexpress | Listing Gone | 5 |  | 2.18
RJ45 Keystone Jack | Temu | https://share.temu.com/JZUGjvaZ1yB | 10 |  | 5.08
Adhesive Cable Clips | Temu | https://share.temu.com/6uqy8Ea9hlB | 50 |  | 1.72
Heat Shrink Sleeve | Temu | https://share.temu.com/fDNtoYvDNAB | 580 |  | 2.69
Welding Heat Shrink | Temu | https://share.temu.com/GA9BiFD1OMB | 1 |  | 4.91
JST Connectors and Cables | Temu | https://share.temu.com/TebOnDVClAB | 1 |  | 4.76
Breadboard | Temu | Listing Gone | 1 |  | 1.19
USB C PD Board | Aliexpress | https://a.aliexpress.com/_EyiGVhm | 5 |  | 4.71
Temperature Humidity and CO2 Sensor(ENS160+AHT21) | Aliexpress | https://a.aliexpress.com/_EvACRI0 | 1 |  | 4.85
Pi Pico | Aliexpress | https://a.aliexpress.com/_EzoM1ms | 5 |  | 9.00
Level Shifter | Aliexpress | https://a.aliexpress.com/_EJrloz2 | 10 |  | 2.28
Ikea BITTERGURKA | Ikea | https://www.ikea.com/ie/en/p/bittergurka-plant-pot-white-80285787/ | 1 | 12 | 12
Ikea ÅKERBÄR | Ikea | https://www.ikea.com/ie/en/p/akerbaer-greenhouse-in-outdoor-white-30537170/ | 1 | 19 | 19
TOTAL |  |  |  |  | 112.01

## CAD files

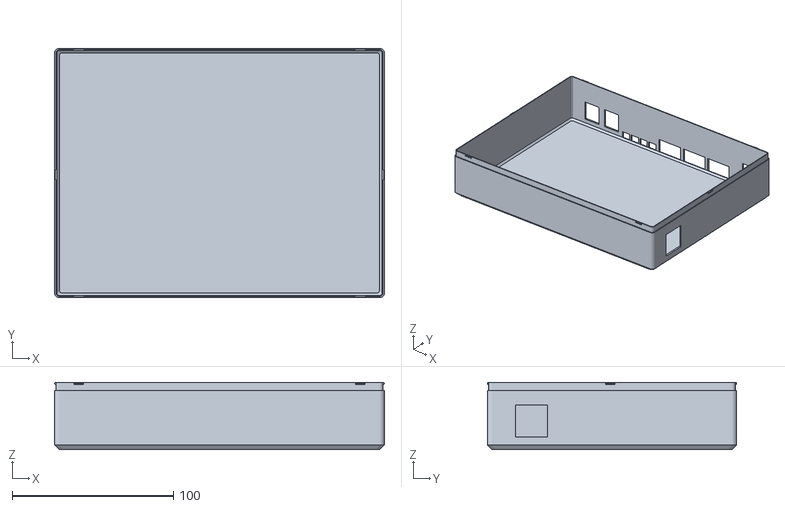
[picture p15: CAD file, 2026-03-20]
3d-models/enclosure/design-v3-bottom.stl
204.8 x 154.8 x 41.8

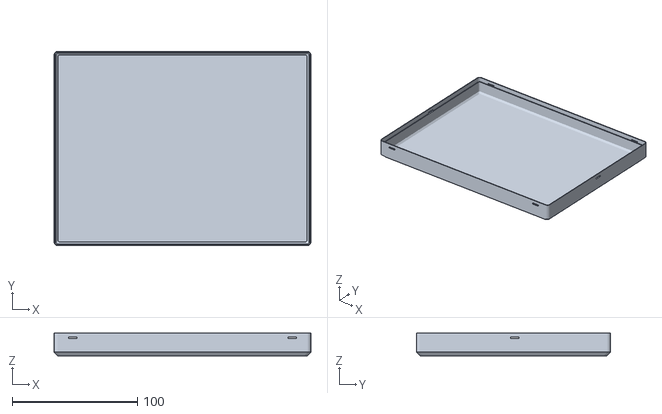
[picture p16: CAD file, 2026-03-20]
3d-models/enclosure/design-v3-lid.stl
204.8 x 154.8 x 18.3

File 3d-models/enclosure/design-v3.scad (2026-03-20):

include <./library/YAPPgenerator_v3.scad>
// ============================================================
//  TWO BREADBOARD ENCLOSURE – YAPP v3 - VERSION 2
//  Internal size for 2× 170×60 boards, sticky-backed
// ============================================================
// ---------- PRINT ----------
printBaseShell      = true;
printLidShell       = false;
// ---------- THICKNESSES ----------
wallThickness       = 1.4;
basePlaneThickness  = 1.8;
lidPlaneThickness   = 1.8;
// ---------- INTERNAL HEIGHT (>= 40 mm REQUIRED) ----------
baseWallHeight      = 40;
lidWallHeight       = 12;
// ---------- INTERNAL FOOTPRINT ----------
pcbLength           = 200;
pcbWidth            = 150;
pcbThickness        = 0;   // irrelevant (no PCB logic used)
// ---------- PADDING ----------
paddingFront        = 1;
paddingBack         = 1;
paddingLeft         = 1;
paddingRight        = 1;
// ---------- LID OVERLAP ----------
ridgeHeight         = 5;
ridgeSlack          = 0.2;
// ---------- COSMETICS ----------
roundRadius         = 3.0;
// ---------- PRINTER ----------
printerLayerHeight  = 0.2;
// ============================================================
//  VIEW / DEBUG
// ============================================================
showSideBySide        = true;
previewQuality        = 6;
renderQuality         = 8;
onLidGap              = 4;
shiftLid              = 6;
colorLid              = "LightGray";
colorBase             = "Gainsboro";
showOrientation       = true;
showPCB               = false;
// ============================================================
//  CUTOUTS – RIGHT WALL 
//  All holes condensed on one side:
//  - 4× RJ45 keystone (14.5×16mm, elevated for clip) - 2 front, 2 back
//  - 4× JST 2-pin female (7.6×5.9mm, long side horizontal)
//  - 3× USB PD trigger boards (22×12mm)
// ============================================================
cutoutsRight =
[
    // === RJ45 KEYSTONES - FRONT SIDE (2×) ===
    [20,                   // horizontal position
     12,                   // vertical center raised for clip
     14.5, 16,             // width × height
     0,
     yappRectangle,
     yappCenter],
    
    [40,                   // horizontal position
     12,                   // vertical center raised for clip
     14.5, 16,             // width × height
     0,
     yappRectangle,
     yappCenter],
    
    // === RJ45 KEYSTONES - BACK SIDE ===

    [182,                  // mirrored position (202 - 20)
     12,                   // vertical center raised for clip
     14.5, 16,             // width × height
     0,
     yappRectangle,
     yappCenter],
    
    // === JST 2-PIN CONNECTORS (4×, 7.6×5.9mm, long side horizontal) ===
    [55,                   // horizontal position
     3,                    // vertical center (flush with floor)
     7.6, 5.9,             // width × height (long side = 7.6mm horizontal)
     0,
     yappRectangle,
     yappCenter],
    
    [64,                   // horizontal position
     3,                    // vertical center
     7.6, 5.9,
     0,
     yappRectangle,
     yappCenter],
    
    [73,                   // horizontal position
     3,                    // vertical center
     7.6, 5.9,
     0,
     yappRectangle,
     yappCenter],
    
    [82,                   // horizontal position
     3,                    // vertical center
     7.6, 5.9,
     0,
     yappRectangle,
     yappCenter],
    
    // === USB PD TRIGGER BOARDS (3×, 22×12mm) ===
    [100,                  // horizontal position
     6,                    // vertical center = 12/2 = 6
     22, 12,               // width × height
     0,
     yappRectangle,
     yappCenter],
    
    [125,                  // horizontal position
     6,                    // vertical center
     22, 12,
     0,
     yappRectangle,
     yappCenter],
    
    [150,                  // horizontal position
     6,                    // vertical center
     22, 12,
     0,
     yappRectangle,
     yappCenter]
];

// ============================================================
//  CUTOUTS – Front WALL
//  Access hole: 25mm from back, 5mm from floor
// ============================================================
cutoutsBack =
[
    [127,                  // 25mm from the edge
     5,                    // 5mm from floor
     20,                   // width
     20,                   // height  
     0,
     yappRectangle]
];
// ---------- UNUSED FACES ----------
cutoutsBase  = [];
cutoutsLid   = [];
cutoutsFront = [];
cutoutsBack  = [];
// ============================================================
//  SNAP JOINTS
// ============================================================
// Symmetric snaps, sized for large enclosure
snapJoins =
[
    [12, 6, yappLeft, yappRight, yappSymmetric],
    [(shellWidth/2)-4, 6, yappFront],
    [(shellWidth/2)-4, 6, yappBack]
];
// ============================================================
//  LABELS (NONE)
// ============================================================
labelsPlane = [];
// ============================================================
//  GENERATE
// ============================================================
YAPPgenerate();

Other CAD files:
3d-models/enclosure/design-v1.scad
3d-models/enclosure/design-v2.scad

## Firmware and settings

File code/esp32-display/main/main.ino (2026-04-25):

/*  Smart Greenhouse Control System with UART Communication
    ESP32-2432S028R (Cheap Yellow Display) + Raspberry Pi Pico W
    
    ESP32 handles: UI Display, Touch Input, UART Communication
    Pico handles: Sensors, Actuators, Control Logic
*/

#include <lvgl.h>
#include <TFT_eSPI.h>
#include <XPT2046_Touchscreen.h>

// UART Communication pins (P3 connector)
#define RX_P3 35
#define TX_P3 22

// Touchscreen pins
#define XPT2046_IRQ 36   // T_IRQ
#define XPT2046_MOSI 32  // T_DIN
#define XPT2046_MISO 39  // T_OUT
#define XPT2046_CLK 25   // T_CLK
#define XPT2046_CS 33    // T_CS

SPIClass touchscreenSPI = SPIClass(VSPI);
XPT2046_Touchscreen touchscreen(XPT2046_CS, XPT2046_IRQ);

#define SCREEN_WIDTH 240
#define SCREEN_HEIGHT 320
// After 270° rotation, logical dimensions are swapped
#define ROTATED_WIDTH 320
#define ROTATED_HEIGHT 240

#define DRAW_BUF_SIZE (SCREEN_WIDTH * SCREEN_HEIGHT / 10 * (LV_COLOR_DEPTH / 8))
uint32_t draw_buf[DRAW_BUF_SIZE / 4];

/* ---------------- SYSTEM STATE ---------------- */
struct SensorData {
  float temperature = 0.0;
  float humidity = 0.0;
  float soil_moisture = 0.0;
  float water_level = 0.0;
  unsigned long last_update = 0;
} sensors;

struct SystemState {
  bool watering_active = false;
  bool lighting_active = false;
  bool air_active = false;
} controls;

/* ---------------- UI ELEMENTS ---------------- */
lv_obj_t *tabview;
lv_obj_t *water_btn, *light_btn, *air_btn;
lv_obj_t *water_led, *light_led, *air_led;
lv_obj_t *temp_label, *humidity_label, *soil_label, *water_label;

// Manual control elements (Options page)
lv_obj_t *manual_led_btn, *manual_fan_btn, *manual_pump_btn;
lv_obj_t *manual_led_indicator, *manual_fan_indicator;

struct ManualState {
  bool led_on = false;
  bool fan_on = false;
} manual;

/* ---------------- UART COMMUNICATION ---------------- */
void sendCommand(const char* command) {
  Serial2.println(command);
  Serial.println("Sent to Pico: " + String(command));
}

void processIncomingData() {
  while (Serial2.available()) {
    String line = Serial2.readStringUntil('\n');
    line.trim();
    if (line.length() > 0) {
      Serial.println("From Pico: " + line);
      
      // Parse sensor data: SENSOR:TYPE:VALUE
    if (line.startsWith("SENSOR:")) {
      // SENSOR:TEMP:24.5
      int p1 = line.indexOf(':');
      int p2 = line.indexOf(':', p1 + 1);

      if (p1 > 0 && p2 > 0) {
        String sensor_type = line.substring(p1 + 1, p2);
        float value = line.substring(p2 + 1).toFloat();

        if (sensor_type == "TEMP") {
          sensors.temperature = value;
        } else if (sensor_type == "HUMIDITY") {
          sensors.humidity = value;
        } else if (sensor_type == "SOIL") {
          sensors.soil_moisture = value;
        } else if (sensor_type == "WATER") {
          sensors.water_level = value;
        }

        sensors.last_update = millis();
        updateDashboard();
      }
    }
      
      // Parse status updates: STATUS:SYSTEM:STATE
      else if (line.startsWith("STATUS:")) {
        int first_colon = line.indexOf(':', 7);
        int second_colon = line.indexOf(':', first_colon + 1);
        
        if (first_colon > 0 && second_colon > 0) {
          String system = line.substring(7, first_colon);
          String state = line.substring(second_colon + 1);
          
          if (system == "WATER") {
            controls.watering_active = (state == "ON");
            updateControlLED(water_led, water_btn, controls.watering_active);
          } else if (system == "LIGHT") {
            controls.lighting_active = (state == "ON");
            updateControlLED(light_led, light_btn, controls.lighting_active);
          } else if (system == "AIR") {
            controls.air_active = (state == "ON");
            updateControlLED(air_led, air_btn, controls.air_active);
          }
        }
      }
    }
  }
}

void requestSensorData() {
  static unsigned long last_request = 0;
  if (millis() - last_request > 5000) { // Request every 5 seconds
    sendCommand("REQ:SENSORS");
    last_request = millis();
  }
}

/* ---------------- UI FUNCTIONS ---------------- */
void log_print(lv_log_level_t level, const char * buf) {
  LV_UNUSED(level);
  Serial.println(buf);
  Serial.flush();
}

void touchscreen_read(lv_indev_t * indev, lv_indev_data_t * data) {
  if(touchscreen.tirqTouched() && touchscreen.touched()) {
    TS_Point p = touchscreen.getPoint();
    int x = map(p.x, 200, 3700, 1, SCREEN_WIDTH);
    int y = map(p.y, 240, 3800, 1, SCREEN_HEIGHT);

    data->state = LV_INDEV_STATE_PRESSED;
    data->point.x = x;
    data->point.y = y;

    Serial.print("Touch: X=");
    Serial.print(x);
    Serial.print(" Y=");
    Serial.println(y);
  } else {
    data->state = LV_INDEV_STATE_RELEASED;
  }
}

void set_led(lv_obj_t *led, bool on) {
  lv_obj_set_style_bg_color(
    led, on ? lv_color_hex(0x00FF00) : lv_color_hex(0xFF0000), 0
  );
}

void updateControlLED(lv_obj_t *led, lv_obj_t *btn, bool active) {
  set_led(led, active);
  lv_label_set_text(lv_obj_get_child(btn, 0), active ? "Turn Off" : "Turn On");
}

/* ---------------- CONTROL CALLBACKS ---------------- */
static void water_cb(lv_event_t * e) {
  lv_event_code_t code = lv_event_get_code(e);
  if(code == LV_EVENT_CLICKED) {
    controls.watering_active = !controls.watering_active;
    sendCommand(controls.watering_active ? "CMD:WATER:ON" : "CMD:WATER:OFF");
    updateControlLED(water_led, water_btn, controls.watering_active);
    LV_LOG_USER("Watering System %s", controls.watering_active ? "ON" : "OFF");
  }
}

static void light_cb(lv_event_t * e) {
  lv_event_code_t code = lv_event_get_code(e);
  if(code == LV_EVENT_CLICKED) {
    controls.lighting_active = !controls.lighting_active;
    sendCommand(controls.lighting_active ? "CMD:LIGHT:ON" : "CMD:LIGHT:OFF");
    updateControlLED(light_led, light_btn, controls.lighting_active);
    LV_LOG_USER("Lighting System %s", controls.lighting_active ? "ON" : "OFF");
  }
}

static void air_cb(lv_event_t * e) {
  lv_event_code_t code = lv_event_get_code(e);
  if(code == LV_EVENT_CLICKED) {
    controls.air_active = !controls.air_active;
    sendCommand(controls.air_active ? "CMD:AIR:ON" : "CMD:AIR:OFF");
    updateControlLED(air_led, air_btn, controls.air_active);
    LV_LOG_USER("Air Quality System %s", controls.air_active ? "ON" : "OFF");
  }
}

/* ---------------- MANUAL CONTROL CALLBACKS (Options page) ---------------- */
static void manual_led_cb(lv_event_t * e) {
  lv_event_code_t code = lv_event_get_code(e);
  if(code == LV_EVENT_CLICKED) {
    manual.led_on = !manual.led_on;
    sendCommand(manual.led_on ? "CMD:LED:ON" : "CMD:LED:OFF");
    set_led(manual_led_indicator, manual.led_on);
    lv_label_set_text(lv_obj_get_child(manual_led_btn, 0), manual.led_on ? "Turn Off" : "Turn On");
    LV_LOG_USER("Manual LED %s", manual.led_on ? "ON" : "OFF");
  }
}

static void manual_fan_cb(lv_event_t * e) {
  lv_event_code_t code = lv_event_get_code(e);
  if(code == LV_EVENT_CLICKED) {
    manual.fan_on = !manual.fan_on;
    sendCommand(manual.fan_on ? "CMD:FAN:ON" : "CMD:FAN:OFF");
    set_led(manual_fan_indicator, manual.fan_on);
    lv_label_set_text(lv_obj_get_child(manual_fan_btn, 0), manual.fan_on ? "Turn Off" : "Turn On");
    LV_LOG_USER("Manual Fan %s", manual.fan_on ? "ON" : "OFF");
  }
}

static void manual_pump_cb(lv_event_t * e) {
  lv_event_code_t code = lv_event_get_code(e);
  if(code == LV_EVENT_CLICKED) {
    // Pump triggers a short pulse - send command and Pico handles the timing
    sendCommand("CMD:PUMP:PULSE");
    LV_LOG_USER("Manual Pump PULSE triggered");
  }
}

/* ---------------- DASHBOARD FUNCTIONS ---------------- */
void dashboard_row(lv_obj_t *parent, int y, const char *label, const char *value, 
                   lv_color_t indicator_color, lv_obj_t **value_label) {
  lv_obj_t *row = lv_obj_create(parent);
  lv_obj_set_width(row, lv_pct(100));
  lv_obj_set_height(row, 40);
  lv_obj_set_pos(row, 0, y);
  lv_obj_set_style_pad_all(row, 6, 0);
  lv_obj_set_style_bg_color(row, lv_color_hex(0xF0F0F0), 0);
  lv_obj_set_style_border_width(row, 1, 0);
  lv_obj_set_style_border_color(row, lv_color_hex(0xDDDDDD), 0);
  lv_obj_remove_flag(row, LV_OBJ_FLAG_SCROLLABLE);
  lv_obj_clear_flag(row, LV_OBJ_FLAG_GESTURE_BUBBLE);

  // Label on the left
  lv_obj_t *lbl = lv_label_create(row);
  lv_label_set_text(lbl, label);
  lv_obj_set_style_text_color(lbl, lv_color_hex(0x333333), 0);
  lv_obj_align(lbl, LV_ALIGN_LEFT_MID, 8, 0);

  // Value on the right - store reference for updates
  *value_label = lv_label_create(row);
  lv_label_set_text(*value_label, value);
  lv_obj_set_style_text_color(*value_label, lv_color_hex(0x000000), 0);
  lv_obj_set_style_text_font(*value_label, &lv_font_montserrat_14, 0);
  lv_obj_align(*value_label, LV_ALIGN_RIGHT_MID, -30, 0);

  // Color indicator circle
  lv_obj_t *indicator = lv_obj_create(row);
  lv_obj_set_size(indicator, 16, 16);
  lv_obj_align(indicator, LV_ALIGN_RIGHT_MID, -6, 0);
  lv_obj_set_style_radius(indicator, LV_RADIUS_CIRCLE, 0);
  lv_obj_set_style_bg_color(indicator, indicator_color, 0);
  lv_obj_set_style_border_width(indicator, 0, 0);
}

void create_dashboard(lv_obj_t *parent) {
  dashboard_row(parent, 15,  "Temperature", "--°C", lv_color_hex(0xFF6B35), &temp_label);
  dashboard_row(parent, 65,  "Humidity", "--%", lv_color_hex(0x4D96FF), &humidity_label);
  dashboard_row(parent, 115, "Soil Moisture", "--%", lv_color_hex(0x8D6E63), &soil_label);
  dashboard_row(parent, 165, "Water Level", "--%", lv_color_hex(0x1E88E5), &water_label);
}

void updateDashboard() {
  char buffer[16];
  
  snprintf(buffer, sizeof(buffer), "%.1f°C", sensors.temperature);
  lv_label_set_text(temp_label, buffer);
  
  snprintf(buffer, sizeof(buffer), "%.0f%%", sensors.humidity);
  lv_label_set_text(humidity_label, buffer);
  
  snprintf(buffer, sizeof(buffer), "%.0f%%", sensors.soil_moisture);
  lv_label_set_text(soil_label, buffer);
  
  snprintf(buffer, sizeof(buffer), "%.0f%%", sensors.water_level);
  lv_label_set_text(water_label, buffer);
}

/* ---------------- AUTO ROW FUNCTIONS ---------------- */
void auto_row(lv_obj_t *parent, int y, const char *name,
                 lv_event_cb_t cb, lv_obj_t **btn, lv_obj_t **led) {

  lv_obj_t *row = lv_obj_create(parent);
  lv_obj_set_width(row, lv_pct(100));
  lv_obj_set_height(row, 36);
  lv_obj_set_pos(row, 0, y);
  lv_obj_set_style_pad_all(row, 4, 0);
  lv_obj_remove_flag(row, LV_OBJ_FLAG_SCROLLABLE);
  lv_obj_clear_flag(row, LV_OBJ_FLAG_GESTURE_BUBBLE);

  lv_obj_t *lbl = lv_label_create(row);
  lv_label_set_text(lbl, name);
  lv_obj_align(lbl, LV_ALIGN_LEFT_MID, 4, 0);

  *btn = lv_button_create(row);
  lv_obj_set_size(*btn, 70, 26);
  lv_obj_align(*btn, LV_ALIGN_RIGHT_MID, -30, 0);
  lv_obj_add_event_cb(*btn, cb, LV_EVENT_CLICKED, NULL);
  lv_obj_clear_flag(*btn, LV_OBJ_FLAG_GESTURE_BUBBLE);

  lv_obj_t *btxt = lv_label_create(*btn);
  lv_label_set_text(btxt, "Turn On");
  lv_obj_center(btxt);

  *led = lv_obj_create(row);
  lv_obj_set_size(*led, 14, 14);
  lv_obj_align(*led, LV_ALIGN_RIGHT_MID, -6, 0);
  lv_obj_set_style_radius(*led, LV_RADIUS_CIRCLE, 0);
  set_led(*led, false);
}

void create_auto(lv_obj_t *parent) {
  // Header label
  lv_obj_t *header = lv_label_create(parent);
  lv_label_set_text(header, "Automatic System Control");
  lv_obj_set_style_text_font(header, &lv_font_montserrat_14, 0);
  lv_obj_align(header, LV_ALIGN_TOP_MID, 0, 5);
  
  // Watering System - trigger condition
  lv_obj_t *water_trigger = lv_label_create(parent);
  lv_label_set_text(water_trigger, "Soil dry & water available");
  lv_obj_set_style_text_font(water_trigger, &lv_font_montserrat_10, 0);
  lv_obj_set_style_text_color(water_trigger, lv_color_hex(0x666666), 0);
  lv_obj_set_pos(water_trigger, 10, 28);
  
  auto_row(parent, 40,  "Watering System", water_cb, &water_btn, &water_led);
  
  // Lighting System - trigger condition
  lv_obj_t *light_trigger = lv_label_create(parent);
  lv_label_set_text(light_trigger, "Ambient light low");
  lv_obj_set_style_text_font(light_trigger, &lv_font_montserrat_10, 0);
  lv_obj_set_style_text_color(light_trigger, lv_color_hex(0x666666), 0);
  lv_obj_set_pos(light_trigger, 10, 82);
  
  auto_row(parent, 94,  "Lighting System", light_cb, &light_btn, &light_led);
  
  // Air Quality System - trigger condition
  lv_obj_t *air_trigger = lv_label_create(parent);
  lv_label_set_text(air_trigger, "Temp >25C or Humidity >70%/<50%");
  lv_obj_set_style_text_font(air_trigger, &lv_font_montserrat_10, 0);
  lv_obj_set_style_text_color(air_trigger, lv_color_hex(0x666666), 0);
  lv_obj_set_pos(air_trigger, 10, 136);
  
  auto_row(parent, 148, "Air Quality System", air_cb, &air_btn, &air_led);
}

/* ---------------- MANUAL PAGE FUNCTIONS ---------------- */
void manual_toggle_row(lv_obj_t *parent, int y, const char *name,
                        lv_event_cb_t cb, lv_obj_t **btn, lv_obj_t **indicator) {
  lv_obj_t *row = lv_obj_create(parent);
  lv_obj_set_width(row, lv_pct(100));
  lv_obj_set_height(row, 36);
  lv_obj_set_pos(row, 0, y);
  lv_obj_set_style_pad_all(row, 4, 0);
  lv_obj_remove_flag(row, LV_OBJ_FLAG_SCROLLABLE);
  lv_obj_clear_flag(row, LV_OBJ_FLAG_GESTURE_BUBBLE);

  lv_obj_t *lbl = lv_label_create(row);
  lv_label_set_text(lbl, name);
  lv_obj_align(lbl, LV_ALIGN_LEFT_MID, 4, 0);

  *btn = lv_button_create(row);
  lv_obj_set_size(*btn, 70, 26);
  lv_obj_align(*btn, LV_ALIGN_RIGHT_MID, -30, 0);
  lv_obj_add_event_cb(*btn, cb, LV_EVENT_CLICKED, NULL);
  lv_obj_clear_flag(*btn, LV_OBJ_FLAG_GESTURE_BUBBLE);

  lv_obj_t *btxt = lv_label_create(*btn);
  lv_label_set_text(btxt, "Turn On");
  lv_obj_center(btxt);

  *indicator = lv_obj_create(row);
  lv_obj_set_size(*indicator, 14, 14);
  lv_obj_align(*indicator, LV_ALIGN_RIGHT_MID, -6, 0);
  lv_obj_set_style_radius(*indicator, LV_RADIUS_CIRCLE, 0);
  set_led(*indicator, false);
}

void manual_trigger_row(lv_obj_t *parent, int y, const char *name,
                         lv_event_cb_t cb, lv_obj_t **btn) {
  lv_obj_t *row = lv_obj_create(parent);
  lv_obj_set_width(row, lv_pct(100));
  lv_obj_set_height(row, 36);
  lv_obj_set_pos(row, 0, y);
  lv_obj_set_style_pad_all(row, 4, 0);
  lv_obj_remove_flag(row, LV_OBJ_FLAG_SCROLLABLE);
  lv_obj_clear_flag(row, LV_OBJ_FLAG_GESTURE_BUBBLE);

  lv_obj_t *lbl = lv_label_create(row);
  lv_label_set_text(lbl, name);
  lv_obj_align(lbl, LV_ALIGN_LEFT_MID, 4, 0);

  *btn = lv_button_create(row);
  lv_obj_set_size(*btn, 70, 26);
  lv_obj_align(*btn, LV_ALIGN_RIGHT_MID, -6, 0);
  lv_obj_add_event_cb(*btn, cb, LV_EVENT_CLICKED, NULL);
  lv_obj_clear_flag(*btn, LV_OBJ_FLAG_GESTURE_BUBBLE);
  lv_obj_set_style_bg_color(*btn, lv_color_hex(0x2196F3), 0);

  lv_obj_t *btxt = lv_label_create(*btn);
  lv_label_set_text(btxt, "Trigger");
  lv_obj_center(btxt);
}

void create_manual(lv_obj_t *parent) {
void create_manual(lv_obj_t *parent) {
  // Header label
  lv_obj_t *header = lv_label_create(parent);
  lv_label_set_text(header, "Manual Device Control");
  lv_obj_set_style_text_font(header, &lv_font_montserrat_14, 0);
  lv_obj_align(header, LV_ALIGN_TOP_MID, 0, 5);

  // LED toggle (on/off)
  manual_toggle_row(parent, 30, "LED Light", manual_led_cb, &manual_led_btn, &manual_led_indicator);
  
  // Fan toggle (on/off)
  manual_toggle_row(parent, 75, "Fan", manual_fan_cb, &manual_fan_btn, &manual_fan_indicator);
  
  // Pump trigger (momentary pulse)
  manual_trigger_row(parent, 120, "Pump", manual_pump_cb, &manual_pump_btn);
}

/* ---------------- GUI SETUP ---------------- */
void create_gui() {
  tabview = lv_tabview_create(lv_screen_active());
  lv_obj_set_size(tabview, ROTATED_WIDTH, ROTATED_HEIGHT);
  lv_tabview_set_tab_bar_size(tabview, 26);

  lv_obj_t *dash = lv_tabview_add_tab(tabview, "Dashboard");
  lv_obj_t *ctrl = lv_tabview_add_tab(tabview, "Auto");
  lv_obj_t *opts = lv_tabview_add_tab(tabview, "Manual");

  lv_obj_set_style_pad_top(dash, 8, 0);
  lv_obj_set_style_pad_top(ctrl, 8, 0);
  lv_obj_set_style_pad_top(opts, 8, 0);

  create_dashboard(dash);
  create_auto(ctrl);
  create_manual(opts);
}

/* ---------------- MAIN SETUP AND LOOP ---------------- */
void setup() {
  Serial.begin(115200);
  Serial2.begin(115200, SERIAL_8N1, RX_P3, TX_P3); // UART to Pico
  
  Serial.println("Smart Greenhouse Control System Starting...");
  Serial.println("ESP32 Display + Pico Communication");
  
  lv_init();
  lv_log_register_print_cb(log_print);

  // Initialize touchscreen
  touchscreenSPI.begin(XPT2046_CLK, XPT2046_MISO, XPT2046_MOSI, XPT2046_CS);
  touchscreen.begin(touchscreenSPI);
  touchscreen.setRotation(2);

  // Initialize display
  lv_display_t *disp = lv_tft_espi_create(SCREEN_WIDTH, SCREEN_HEIGHT, draw_buf, sizeof(draw_buf));
  lv_display_set_rotation(disp, LV_DISPLAY_ROTATION_270);

  // Initialize input device
  lv_indev_t *indev = lv_indev_create();
  lv_indev_set_type(indev, LV_INDEV_TYPE_POINTER);
  lv_indev_set_read_cb(indev, touchscreen_read);

  // Create GUI
  create_gui();
  
  // Request initial sensor data
  delay(1000);
  sendCommand("REQ:SENSORS");
  sendCommand("REQ:STATUS");
  
  Serial.println("System ready!");
}

void loop() {
  static uint32_t last_tick = 0;
  uint32_t now = millis();

  lv_tick_inc(now - last_tick);
  last_tick = now;

  lv_task_handler();

  processIncomingData();
  requestSensorData();

  delay(2);
}

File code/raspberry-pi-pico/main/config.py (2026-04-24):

"""
Smart Greenhouse Configuration
Pin assignments and threshold constants
"""

# ============== PIN ASSIGNMENTS ==============

# Analog Sensors (ADC pins)
SOIL_MOISTURE_PIN = 26      # GP26 Capacitive soil sensor
WATER_LEVEL_PIN = 28        # GP28 Reservoir water level
LIGHT_SENSOR_PIN = 27       # GP27 Light dependent resistor

# I2C Temperature/Humidity Sensor (AHT21/30)
TEMP_HUMIDITY_SCL = 5       # GP5 - I2C clock
TEMP_HUMIDITY_SDA = 4       # GP4 - I2C data

# Relay Outputs (Active LOW)
PUMP_RELAY_PIN = 14         # GP15 - Water pump relay
FAN_RELAY_PIN = 15          # GP14 - Ventilation fan relay
LIGHT_RELAY_PIN = 10        # GP10 - Grow light relay

# UART Communication with ESP32
UART_TX_PIN = 0             # GP0 - UART0 TX
UART_RX_PIN = 1             # GP1 - UART0 RX
UART_BAUDRATE = 115200

# ============== SENSOR THRESHOLDS ==============

# Soil Moisture (Raw ADC values - higher = drier)
# Calibration: AIR ~65000, WATER ~15000
SOIL_DRY_THRESHOLD = 40000  # Above this = soil is dry, needs water

# Water Level (Raw ADC values - higher = more water)
WATER_LOW_THRESHOLD = 15000 # Below this = reservoir is empty

# Temperature (Celsius)
TEMP_HIGH_THRESHOLD = 25.0  # Above this = too hot, turn on fan
TEMP_LOW_THRESHOLD = 20.0   # Below this = too cold, turn off fan to preserve heat

# Humidity (Percentage)
HUMIDITY_HIGH_THRESHOLD = 70.0  # Above this = too humid, turn on fan
HUMIDITY_LOW_THRESHOLD = 50.0   # Below this = too dry, turn on fan to circulate

# Light (Raw ADC values - higher = brighter)
LIGHT_LOW_THRESHOLD = 1000  # Below this = too dark, turn on grow light

# ============== TIMING ==============

# Main loop intervals (milliseconds)
SENSOR_READ_INTERVAL_MS = 2000   # Read sensors every 2 seconds
DATA_SEND_INTERVAL_MS = 5000     # Send data to ESP32 every 5 seconds

# Watering System - Pulse watering to prevent overwatering
PUMP_PULSE_MS = 500              # Duration of each pump burst (500ms)
PUMP_COOLDOWN_MS = 30000         # Minimum time between pulses (30 seconds)

# ============== ADC CALIBRATION ==============

# For converting raw ADC to percentage
ADC_MAX = 65535  # 16-bit ADC maximum value

# Soil moisture calibration (inverted - lower raw = wetter)
SOIL_AIR_VALUE = 65000    # Sensor in air (0% moisture)
SOIL_WATER_VALUE = 15000  # Sensor in water (100% moisture)

# Water level calibration
WATER_EMPTY_VALUE = 10000  # Empty reservoir (0%)
WATER_FULL_VALUE = 50000   # Full reservoir (100%)

# Light sensor calibration
LIGHT_DARK_VALUE = 500     # Complete darkness (0%)
LIGHT_BRIGHT_VALUE = 50000 # Bright light (100%)

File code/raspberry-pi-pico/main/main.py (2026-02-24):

"""
Smart Greenhouse Control System
Raspberry Pi Pico W - Main Entry Point

This is the main entry point for the greenhouse controller.
It initializes all systems and runs the main control loop.

Systems:
- Watering System: Automatic pulse watering based on soil moisture
- Air Quality System: Fan control based on temperature/humidity
- Lighting System: Grow light control based on ambient light

Communication:
- UART to ESP32 display for UI and manual control
"""

from GreenhouseController import GreenhouseController


def main():
    """Main entry point"""
    print("=" * 40)
    print("Smart Greenhouse Control System")
    print("Raspberry Pi Pico W")
    print("=" * 40)
    
    # Create and run the greenhouse controller
    controller = GreenhouseController()
    controller.run()


if __name__ == "__main__":
    main()

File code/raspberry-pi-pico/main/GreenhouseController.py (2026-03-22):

"""
Greenhouse Controller Module
Main orchestrator that coordinates all systems and handles ESP32 communication
"""

import time
from machine import Pin
from UARTCommunication import UARTCommunication
from WateringSystem import WateringSystem
from AirQualitySystem import AirQualitySystem
from LightingSystem import LightingSystem
from config import SENSOR_READ_INTERVAL_MS, DATA_SEND_INTERVAL_MS


class GreenhouseController:
    """
    Main controller that orchestrates all greenhouse systems.
    
    Responsibilities:
    - Initialize all subsystems
    - Run main control loop
    - Process commands from ESP32
    - Send sensor data and status to ESP32
    """
    
    def __init__(self):
        """Initialize all subsystems"""
        print("=" * 50)
        print("[CONTROLLER] Initializing Greenhouse Controller...")
        print("=" * 50)
        
        # Communication
        print("[CONTROLLER] Setting up UART communication...")
        self.uart = UARTCommunication()
        
        # Systems
        print("[CONTROLLER] Initializing Watering System...")
        self.wateringSystem = WateringSystem()
        
        print("[CONTROLLER] Initializing Air Quality System...")
        self.airQualitySystem = AirQualitySystem()
        
        print("[CONTROLLER] Initializing Lighting System...")
        self.lightingSystem = LightingSystem()
        
        # Status LED (onboard)
        self.led = Pin("LED", Pin.OUT)
        
        # Timing
        self.lastSensorRead = 0
        self.lastDataSend = 0
        self.loopCount = 0
        
        print("=" * 50)
        print("[CONTROLLER] Greenhouse Controller initialized!")
        print("=" * 50)
    
    def run(self):
        """Main control loop - runs forever"""
        # Signal ready to ESP32
        print("[CONTROLLER] Sending READY signal to ESP32...")
        self.uart.sendReady()
        
        # Initial sensor read and status send
        print("[CONTROLLER] Performing initial sensor read...")
        time.sleep_ms(500)
        self._readAllSensors()
        self.sendAllSensorData()
        self.sendAllStatus()
        
        print("=" * 50)
        print("[CONTROLLER] Main loop starting...")
        print(f"[CONTROLLER] Sensor read interval: {SENSOR_READ_INTERVAL_MS}ms")
        print(f"[CONTROLLER] Data send interval: {DATA_SEND_INTERVAL_MS}ms")
        print("=" * 50)
        
        while True:
            try:
                currentTime = time.ticks_ms()
                self.loopCount += 1
                
                # Heartbeat LED
                self.led.toggle()
                
                # Process any incoming commands from ESP32
                self._processCommands()
                
                # Read sensors periodically
                if time.ticks_diff(currentTime, self.lastSensorRead) >= SENSOR_READ_INTERVAL_MS:
                    print("")
                    print(f"[CONTROLLER] === Loop #{self.loopCount} - Sensor Read ===")
                    self._readAllSensors()
                    self.lastSensorRead = currentTime
                
                # Update all systems (run automatic control logic)
                self._updateSystems()
                
                # Send data to ESP32 periodically
                if time.ticks_diff(currentTime, self.lastDataSend) >= DATA_SEND_INTERVAL_MS:
                    print("")
                    print("[CONTROLLER] === Sending data to ESP32 ===")
                    self.sendAllSensorData()
                    self._logSystemStatus()
                    self.lastDataSend = currentTime
                
                # Small delay to prevent busy loop
                time.sleep_ms(100)
                
            except Exception as e:
                print(f"[CONTROLLER] ERROR in main loop: {e}")
                # Flash LED rapidly to indicate error
                for _ in range(5):
                    self.led.on()
                    time.sleep_ms(100)
                    self.led.off()
                    time.sleep_ms(100)
    
    def _processCommands(self):
        """Process all pending commands from ESP32"""
        commands = self.uart.receiveAll()
        for cmd in commands:
            self._handleCommand(cmd)
    
    def _handleCommand(self, cmd):
        """Handle a single command from ESP32"""
        print(f"[CONTROLLER] Received command from ESP32: {cmd}")
        
        # Request commands
        if cmd == "REQ:SENSORS":
            print("[CONTROLLER] -> Responding with sensor data")
            self.sendAllSensorData()
            
        elif cmd == "REQ:STATUS":
            print("[CONTROLLER] -> Responding with system status")
            self.sendAllStatus()
        
        # Watering system commands
        elif cmd == "CMD:WATER:ON":
            print("[CONTROLLER] -> Enabling Watering System")
            self.wateringSystem.enable()
            self.uart.sendStatus("WATER", True)
            
        elif cmd == "CMD:WATER:OFF":
            print("[CONTROLLER] -> Disabling Watering System")
            self.wateringSystem.disable()
            self.uart.sendStatus("WATER", False)
        
        # Lighting system commands
        elif cmd == "CMD:LIGHT:ON":
            print("[CONTROLLER] -> Enabling Lighting System")
            self.lightingSystem.enable()
            self.uart.sendStatus("LIGHT", True)
            
        elif cmd == "CMD:LIGHT:OFF":
            print("[CONTROLLER] -> Disabling Lighting System")
            self.lightingSystem.disable()
            self.uart.sendStatus("LIGHT", False)
        
        # Air quality system commands
        elif cmd == "CMD:AIR:ON":
            print("[CONTROLLER] -> Enabling Air Quality System")
            self.airQualitySystem.enable()
            self.uart.sendStatus("AIR", True)
            
        elif cmd == "CMD:AIR:OFF":
            print("[CONTROLLER] -> Disabling Air Quality System")
            self.airQualitySystem.disable()
            self.uart.sendStatus("AIR", False)
        
        # Manual direct device controls (Options page)
        elif cmd == "CMD:LED:ON":
            print("[CONTROLLER] -> Manual LED ON")
            self.lightingSystem.light.turnOn()
            self.lightingSystem.isLightOn = True
            
        elif cmd == "CMD:LED:OFF":
            print("[CONTROLLER] -> Manual LED OFF")
            self.lightingSystem.light.turnOff()
            self.lightingSystem.isLightOn = False
            
        elif cmd == "CMD:FAN:ON":
            print("[CONTROLLER] -> Manual FAN ON")
            self.airQualitySystem.fan.turnOn()
            self.airQualitySystem.isFanOn = True
            
        elif cmd == "CMD:FAN:OFF":
            print("[CONTROLLER] -> Manual FAN OFF")
            self.airQualitySystem.fan.turnOff()
            self.airQualitySystem.isFanOn = False
            
        elif cmd == "CMD:PUMP:PULSE":
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

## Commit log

2026-01-08 feat: add initial relay control code
2026-01-08 feat: create initial platform io project for air sensor
2026-01-08 chore: swiftch to micropython for temp humidity sensor
2026-01-09 feat: add relay trigger code
2026-01-09 feat: add light sensor code
2026-01-09 feat: add light sensor + relay code
2026-01-09 feat: add water level sensor code
2026-01-09 feat: add code for pump + water sensor
2026-01-10 chore: remove esp32 code - we are focusing on using pico with esp32 just for display
2026-01-10 feat: add intial esp32 display code
2026-01-11 feat: add pico and esp32 pinout pics
2026-01-11 feat: add intial test arduino and micropython uart code - tesing communication between esp32 and pi pico
2026-01-18 feat: add pinout diagrams for CYD ESP32-2432S028
2026-01-18 feat: add working uart serial connection between cyd and pico
2026-01-18 docs: mention initial esp32 deps
2026-01-18 feat: improve ui layout - the top tab is perfect except I can no longer click it, I have to swipe to move to the other tab. - the Dashboard and control items are great and perfectly aligned except fo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
    [mock-ui.ino]
2026-01-19 chore: add calibration example
2026-01-19 chore: add debug indicators - for evaluating touch calibration
2026-01-19 chore: add basic button + slider example
2026-01-19 fix: get tabs and buttons working. - content doesn't fill screen
    [mock-ui.ino]
2026-01-19 fix: resolve layout issues - rotation caused content sizing missmatch
    [mock-ui.ino]
2026-01-19 feat: add e2e example - ui on esp32 back and forth to pico - pico uses mocked values
2026-02-01 feat: add version 1 of design
    [design-v1.scad]
2026-02-01 feat: add version 2 of design
    [design-v2.scad]
2026-02-12 feat: new refactored TemperatureAndHumiditySensor
2026-02-12 feat: new refactored relay code
2026-02-13 chore: import adc explicitly
2026-02-14 chore: change TemperatureAndHumiditySensor pins - pins already used by UART
2026-02-14 docs: add enclosure doc
2026-02-24 feat: split main and experimental esp32 code
2026-02-24 feat: add bash script to copy all files to pico
2026-03-04 feat: update relay impl - support active low and high - add additional logging
2026-03-04 chore: update relay pins
2026-03-04 feat: switch from AHT30 to AHT21 - AHT21 is more reliable and is on the same board as cO2 sensor
2026-03-04 chore: update relay creation
2026-03-20 feat: add v3 of enclosure
    [design-v3-bottom.stl, design-v3-lid.stl, design-v3.scad]
2026-03-22 feat: default all systems off - rename button text to be clearer
2026-03-22 feat: add options support to pico
2026-03-22 docs: add arduino info
2026-03-22 fix: led should be active high
    [LightingSystem.py]
2026-04-06 feat: add parts list and costings
    [parts-list-and-cost.csv]
2026-04-24 feat: update thresholds for code and docs - updated values are now - temperature 20-25 - humidity 50-70
